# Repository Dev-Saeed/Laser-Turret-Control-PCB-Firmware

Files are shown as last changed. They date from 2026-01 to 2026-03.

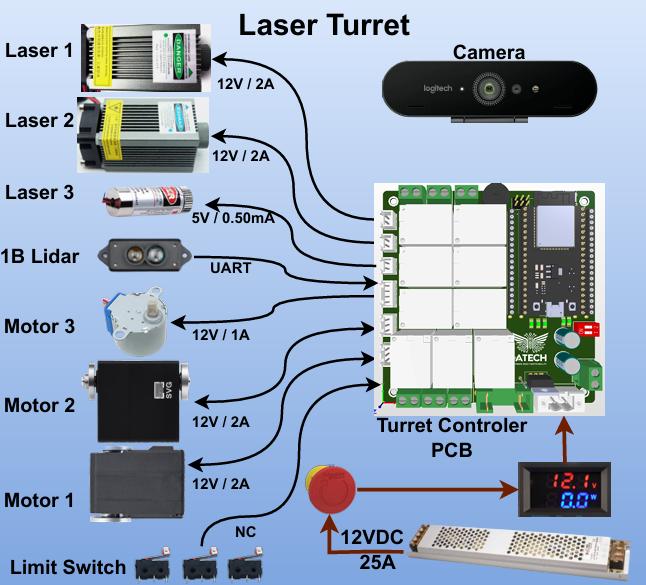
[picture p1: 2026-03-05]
Turret Component.jpg

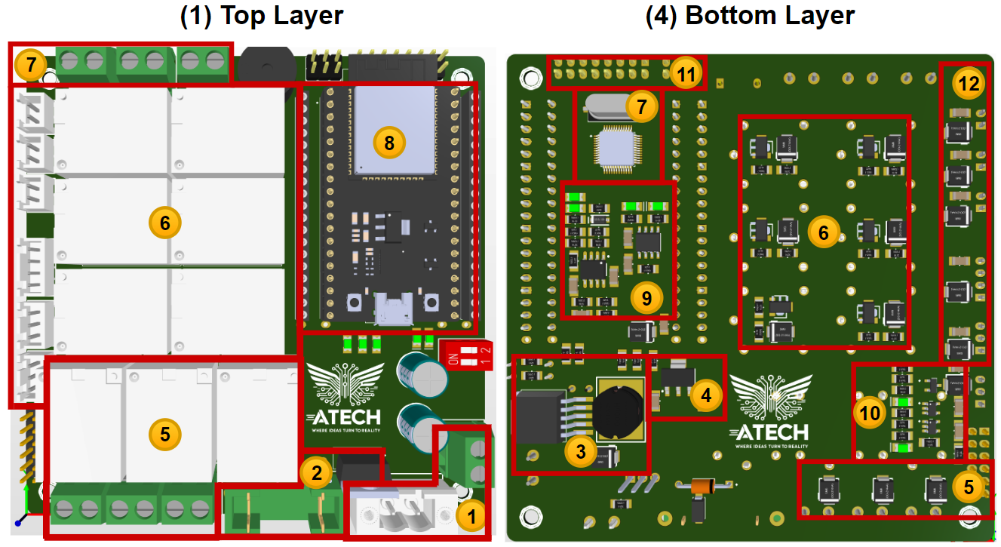
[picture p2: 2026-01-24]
PCB Files/Servo Bus Controller/Component Map.png

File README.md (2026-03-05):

# 🔧 Laser Turret – Embedded Control & PCB Firmware

> **Message Contract First.** All modules talk using **newline-delimited JSON (NDJSON)** over the selected transport (UART / RS485 / CAN with JSON payload). Each JSON object ends with `\n`. Unknown fields are ignored. Missing fields fall back to sane defaults (shown below) inside the firmware via `value | default`.

## 📨 JSON Message Contract (Over Serial/CAN)

### Transport & Framing

* **Physical/Link**: UART (TTL) • RS485 (half-duplex) • CAN (JSON in data field with simple chunking if needed)
* **Encoding**: UTF-8 JSON, **one message per line**, terminated by `\n`
* **Max payload (typ.)**: ≤ 384 bytes for `command`, ≤ 512 bytes for `status` (per current `StaticJsonDocument` sizes)
* **Clocking**: default UART `SERIAL_8N1` (baud per build config)
* **Reliability**: Higher layers may re-send last packet periodically; receivers treat each message as idempotent

---

### ▶️ Command (Control Station ESP32 ➜ Turret ESP32)

**Root shape**

```json
{
  "type": "command",
  "system_enabled": <bool>,
  "motion": {
    "pan_speed_rpm": <float>,
    "pan_min_angle": <float>,
    "pan_max_angle": <float>,
    "tilt_speed_rpm": <float>,
    "tilt_min_angle": <float>,
    "tilt_max_angle": <float>,
    "laser_focus_angle": <float>
  },
  "actuator": {
    "laser1_on": <bool>,
    "laser2_on": <bool>,
    "laser3_on": <bool>,
    "pan_motor_on": <bool>,
    "tilt_motor_on": <bool>,
    "buzzer_on": <bool>
  }
}
```

**Fields**

| Path | Type | Unit | Default | Range / Notes |
| --- | --- | --- | --- | --- |
| `type` | string | – | – | Must be `"command"`. |
| `system_enabled` | bool | – | `false` | Global soft-enable for turret logic. |
| `motion.pan_speed_rpm` | float  | rpm | `0.0` | Desired pan speed (sign = direction). |
| `motion.pan_min_angle` | float  | degrees | `0.0` | Software min limit for pan. |
| `motion.pan_max_angle` | float  | degrees | `0.0` | Software max limit for pan. |
| `motion.tilt_speed_rpm` | float  | rpm | `0.0` | Desired tilt speed (sign = direction).  |
| `motion.tilt_min_angle` | float  | degrees | `0.0` | Software min limit for tilt. |
| `motion.tilt_max_angle` | float  | degrees | `0.0` | Software max limit for tilt. |
| `motion.laser_focus_angle` | float  | degrees | `0.0` | Target focus angle (if used by optics). |
| `actuator.laser1_on` | bool | – | `false` | Relay R1. |
| `actuator.laser2_on` | bool | – | `false` | Relay R2. |
| `actuator.laser3_on` | bool | – | `false` | Relay R3 (aiming beam). |
| `actuator.pan_motor_on` | bool | – | `false` | Relay R4 (Servo/driver power). |
| `actuator.tilt_motor_on` | bool | – | `false` | Relay R5 (Servo/driver power). |
| `actuator.buzzer_on` | bool | – | `false` | Relay R6. |

**Minimal example**

```json
{"type":"command","system_enabled":true,"motion":{"pan_speed_rpm":12.0,"pan_min_angle":-90,"pan_max_angle":90,"tilt_speed_rpm":8.0,"tilt_min_angle":-30,"tilt_max_angle":45,"laser_focus_angle":5.0},"actuator":{"laser1_on":true,"laser2_on":false,"laser3_on":true,"pan_motor_on":true,"tilt_motor_on":true,"buzzer_on":false}}
```

---

### 📤 Status (Turret ESP32 ➜ Control Station / GUI)

**Root shape**

```json
{
  "type": "status",
  "motion": {
    "pan_angle_deg": <float>,
    "tilt_angle_deg": <float>,
    "pan_speed_rpm": <float>,
    "tilt_speed_rpm": <float>,
    "pan_voltage": <float>,
    "tilt_voltage": <float>
  },
  "buttons": {
    "laser_blue": <bool>,
    "laser_green": <bool>,
    "stage1": <bool>,
    "stage2": <bool>,
    "stage3": <bool>,
    "manual_mode": <bool>,
    "confirm_target": <bool>
  },
  "joystick": {
    "pot_pan": <float>,
    "pot_tilt": <float>,
    "pot_focus": <float>,
    "press": <bool>
  }
}
```

> **Note:** The code also reads `buttons.arm` when parsing status (sets `lastStatus.buttons.arm`). If you plan to surface an **arm** indicator, include it under `buttons.arm` in the sender.

**Fields**

| Path | Type | Unit | Default | Range / Notes |
| --- | --- | --- | --- | --- |
| `type` | string | – | – | Must be `"status"`. |
| `motion.pan_angle_deg` | float  | degrees | `0.0` | Measured pan angle. |
| `motion.tilt_angle_deg`  | float  | degrees | `0.0` | Measured tilt angle. |
| `motion.pan_speed_rpm` | float  | rpm | `0.0` | Measured/estimated pan speed. |
| `motion.tilt_speed_rpm`  | float  | rpm | `0.0` | Measured/estimated tilt speed. |
| `motion.pan_voltage` | float  | volts | `0.0` | Driver/sensor reading. |
| `motion.tilt_voltage` | float  | volts | `0.0` | Driver/sensor reading. |
| `buttons.laser_blue` | bool | – | `false` | Panel button state. |
| `buttons.laser_green` | bool | – | `false` | Panel button state. |
| `buttons.stage1` | bool | – | `false` | Mode stage indicator. |
| `buttons.stage2` | bool | – | `false` | Mode stage indicator. |
| `buttons.stage3` | bool | – | `false` | Mode stage indicator. |
| `buttons.manual_mode` | bool | – | `false` | Manual override active. |
| `buttons.confirm_target` | bool | – | `false` | Operator confirmation. |
| `buttons.arm`* | bool | – | `false` | (*Optional but parsed by code.) Global arm latch indicator. |
| `joystick.pot_pan` | float  | 0..1 | `0.0` | Normalized raw input. |
| `joystick.pot_tilt` | float  | 0..1 | `0.0` | Normalized raw input. |
| `joystick.pot_focus` | float  | 0..1 | `0.0` | Normalized raw input. |
| `joystick.press` | bool | – | `false` | Joystick switch. |

**Example**

```json
{"type":"status","motion":{"pan_angle_deg":14.2,"tilt_angle_deg":-3.5,"pan_speed_rpm":10.7,"tilt_speed_rpm":7.9,"pan_voltage":11.8,"tilt_voltage":11.7},"buttons":{"arm":true,"laser_blue":false,"laser_green":true,"stage1":true,"stage2":false,"stage3":false,"manual_mode":false,"confirm_target":true},"joystick":{"pot_pan":0.41,"pot_tilt":0.58,"pot_focus":0.12,"press":false}}
```

---

### Parsing & Robustness Rules

* Messages without `type` are **ignored**.
* Unknown fields are **ignored** (for forward compatibility).
* On `type: "command"` and `type: "status"`, missing inner fields use defaults shown above.
* Receiver processes a full message **only at newline**; partial lines are buffered.
* **Validation**: basic deserialization error check; invalid JSON is dropped silently.
* **Versioning** (recommended): add `"schema":"1.0"` at root in future revisions; receivers should ignore if absent.

---

## 📦 Repository Structure

```bash
├── firmware/
│   ├── control_station_esp32/        # Control station (joystick, buttons, PC communication)
│   │   ├── include/                  # Header files
│   │   │   ├── JsonMessenger.h
│   │   │   └── StationConfig.h
│   │   ├── src/                      # Source files
│   │   │   ├── JsonMessenger.cpp
│   │   │   ├── StationConfig.cpp
│   │   │   └── main.cpp
│   │   ├── lib/                      # External libraries
│   │   └── README
│   │
│   ├── turret_esp32/                 # Main turret logic (motors, laser, feedback)
│   │   ├── include/                  # Header files
│   │   │   ├── JsonMessenger.h
│   │   │   ├── STM_Link.h
│   │   │   ├── SerialSpeedInput.h
│   │   │   ├── TurretConfig.h
│   │   │   ├── ddl_servo.h
│   │   │   ├── nema_driver.h
│   │   │   ├── physics.h
│   │   │   ├── st_driver.h
│   │   │   └── stepper_focus_driver.h
│   │   ├── src/                      # Source files
│   │   │   ├── JsonMessenger.cpp
│   │   │   ├── STM_Link.cpp
│   │   │   ├── TurretConfig.cpp
│   │   │   ├── ddl_servo.cpp
│   │   │   ├── nema_driver.cpp
│   │   │   ├── physics.cpp
│   │   │   ├── st_driver.cpp
│   │   │   ├── stepper_focus_driver.cpp
│   │   │   └── main.cpp
│   │   ├── lib/                      # External libraries (Servo, Dynamixel, etc.)
│   │   │   ├── Dynamixel2Arduino/
│   │   │   ├── SCServo/
│   │   │   └── ServoDriverST/
│   │   └── test/
│   │
│   └── turret_stm32/                 # Low-level I/O, relays, limit switches
│       ├── Core/                     # Application core (HAL, main loop)
│       ├── Drivers/                  # STM32 HAL & BSP drivers
│       ├── metadata/                 # Project metadata
│       ├── settings/                 # Build / configuration files
│       └── Debug/
│
├── pcb/
│   └── turret_control_station_pcb_design/   # Shared PCB for turret & control station
│
├── docs/
│   └── readme_assets/                # Diagrams, schematics, images
│
└── README.md

---

## 🧠 System Architecture

Two microcontroller nodes coordinate turret control and safety via serial messaging.

### 1) ESP32 – Control Station Module

**Reads**

* 3-axis joystick + buttons (GPIO)

**Receives**

* Target parameters from laptop (CV module)

**Sends**

* `command` JSON to Turret Unit (UART / Modbus / CAN)

**Inputs from Laptop**

* Pan/Tilt (angle/velocity), laser enable, mode toggles, buzzer

---

### 2) ESP32 – Turret Unit Module

**Receives**

* `command` JSON from Control Station

**Controls**

* **Relays**: laser modules (x3), servo power (x2), buzzer
* **Pan/Tilt servos** over RS485 (half-duplex, vendor protocol)
* **Stepper motor** (driver or direct)

**Communicates**

* UART with **STM32** for relay/limit I/O
* Sends `status` JSON back to Control Station

**Feedback**

* Motor angles/speeds/temperatures, relay states, safety flags

---

### 3) STM32F0 – Turret Relay & Safety Controller

**Functions**

* Drives **6 relays** via GPIO + transistor stages
* Reads **limit switches** (NO type)
* Handles **EMG** switches that cut **12 V** power electrically (out of MCU loop)

**Relay Map**

| Relay | Load                |
| ----: | ------------------- |
|    R1 | Laser Module 1      |
|    R2 | Laser Module 2      |
|    R3 | Laser Aiming Beam   |
|    R4 | Servo Motor 1 Power |
|    R5 | Servo Motor 2 Power |
|    R6 | Buzzer              |

---

## ⚡ Power & Safety

**Input**: 12 V DC
**Regulation**: 12→5 V (buck), 5→3.3 V (LDO)

**Global Power Relays**

| Relay Group | Purpose                         |
| ----------- | ------------------------------- |
| Main        | Master enable for all actuators |
| Motor       | Enables R4–R5 (servo/driver)    |
| Laser       | Enables R1–R3 (lasers)          |

**Emergency Interfaces**

* External EMG/limit contacts in series with relay coils
* **Closed = enabled**, **open = immediate power cut** to the group

---

## 🔁 Links & Protocols

**Control Station ⇄ Turret**: UART / Modbus (RS485) / CAN; payload is the JSON `command`/`status` above.
**Turret ⇄ STM32**: UART, compact custom messages for relay toggles + limit switch feedback (JSON or binary, depending on build).

---

## 🛠️ Feature Highlights

* ✅ One **unified PCB** used in **both modules**
* ✅ Clean module split: **control**, **execution**, **relay/safety**
* ✅ Multi-bus comms: **Serial**, **Modbus**, **CAN**
* ✅ Hardware **EMG** cutoffs for lasers & motors
* ✅ Manual / CV / Hybrid control modes
* ✅ GPIO headroom for future sensors/actuators

---

## 🧪 Getting Started (Soon)

Step-by-step flashing & wiring guides for:

* ESP32 (Control Station)
* ESP32 (Turret Unit)
* STM32 (Relay Controller)

---

## 🧩 Implementation Notes (from `JsonMessenger`)

* `begin()` sets port & reserves ~512 B buffer.
* `sendCommand()` / `sendStatus()` build JSON via ArduinoJson and append `\n`.
* `receive()` buffers until newline, then `processMessage()`.
* `processMessage()` validates `type` and populates `lastCommand` / `lastStatus`.
* Document sizes: `StaticJsonDocument<384>` (command/status send) and `StaticJsonDocument<512>` (receive/parse).

> **Consistent Button Set:** The parser reads `buttons.arm` in `status`; if you want this latched in UI/safety, emit it from the sender.

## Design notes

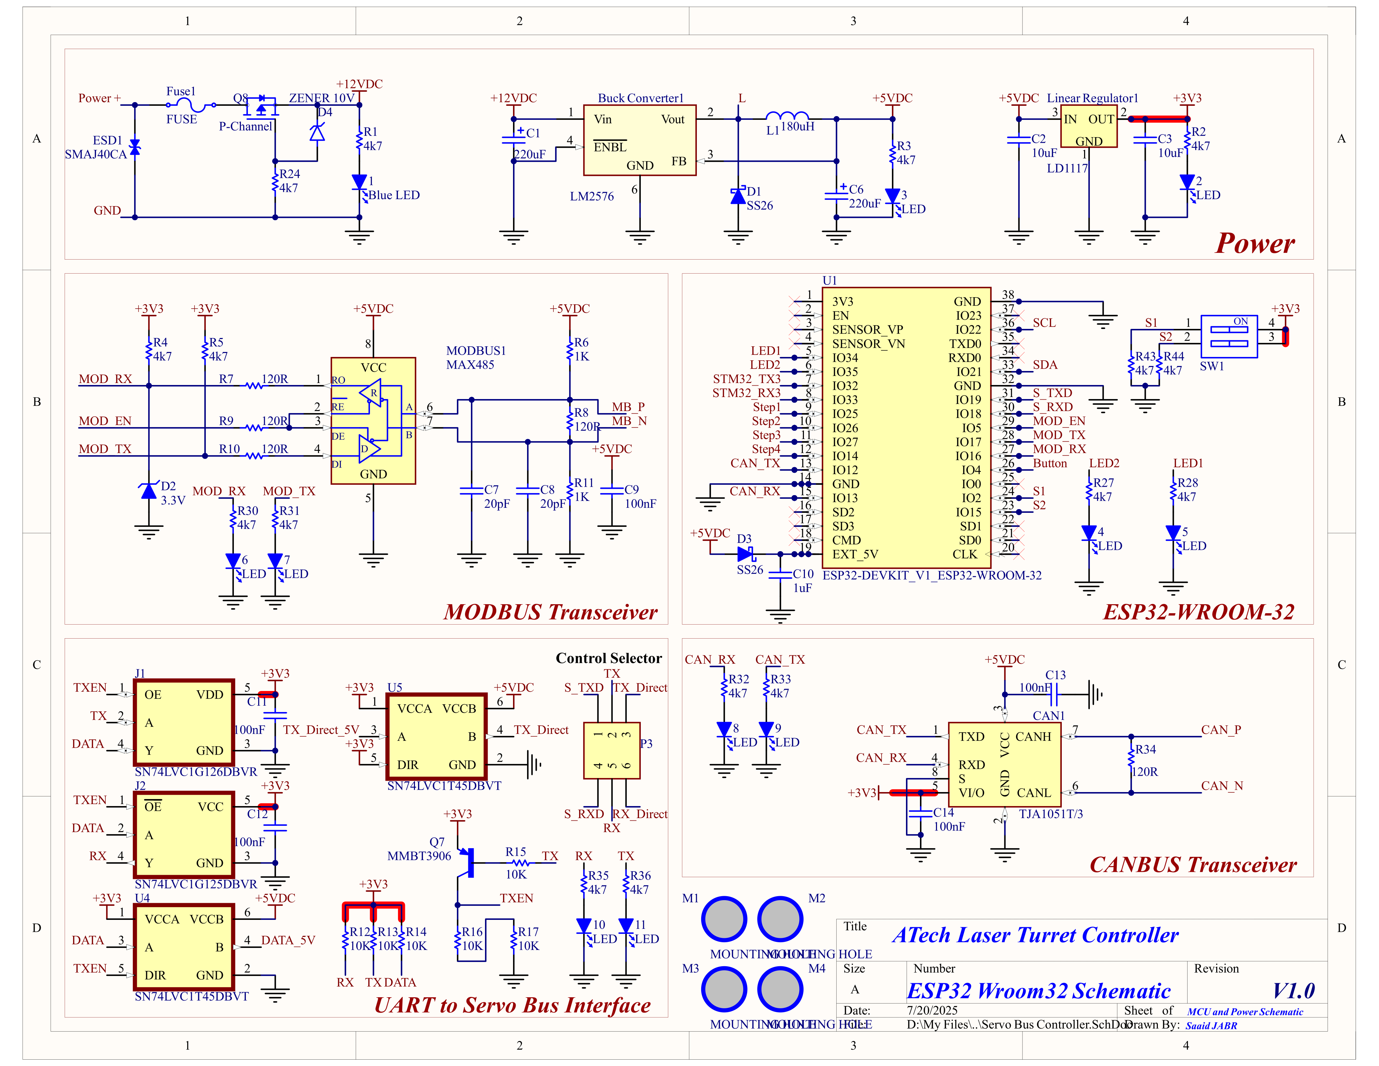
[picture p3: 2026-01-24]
PCB Files/Servo Bus Controller/Laser Turret Controller Schematic - Page 1.png

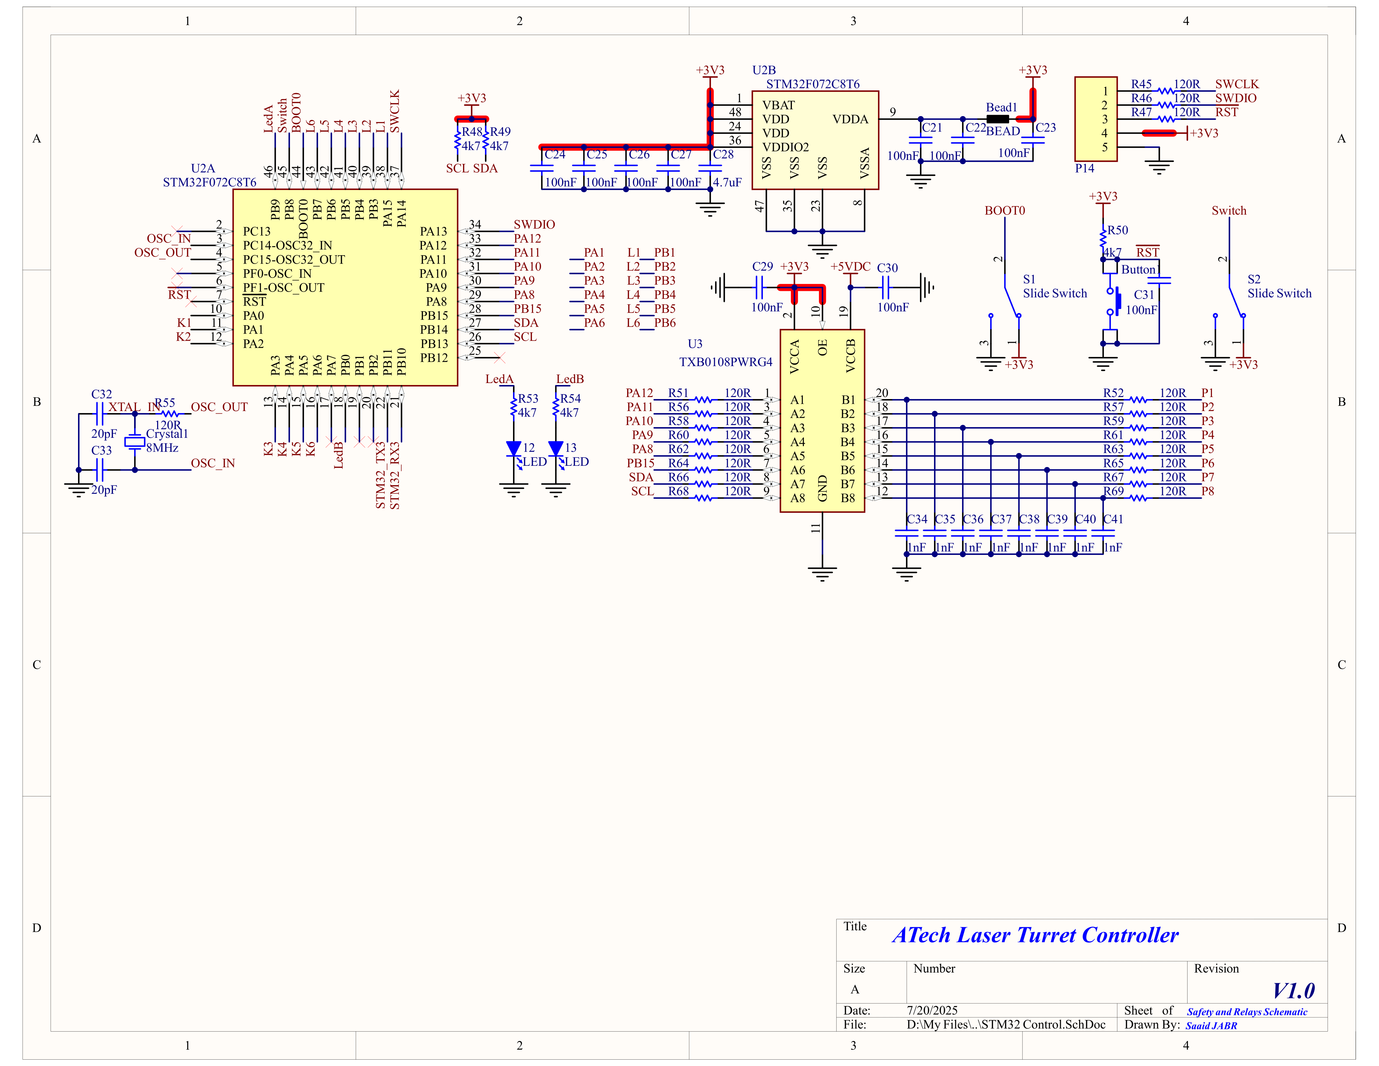
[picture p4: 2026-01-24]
PCB Files/Servo Bus Controller/Laser Turret Controller Schematic - Page 2.png

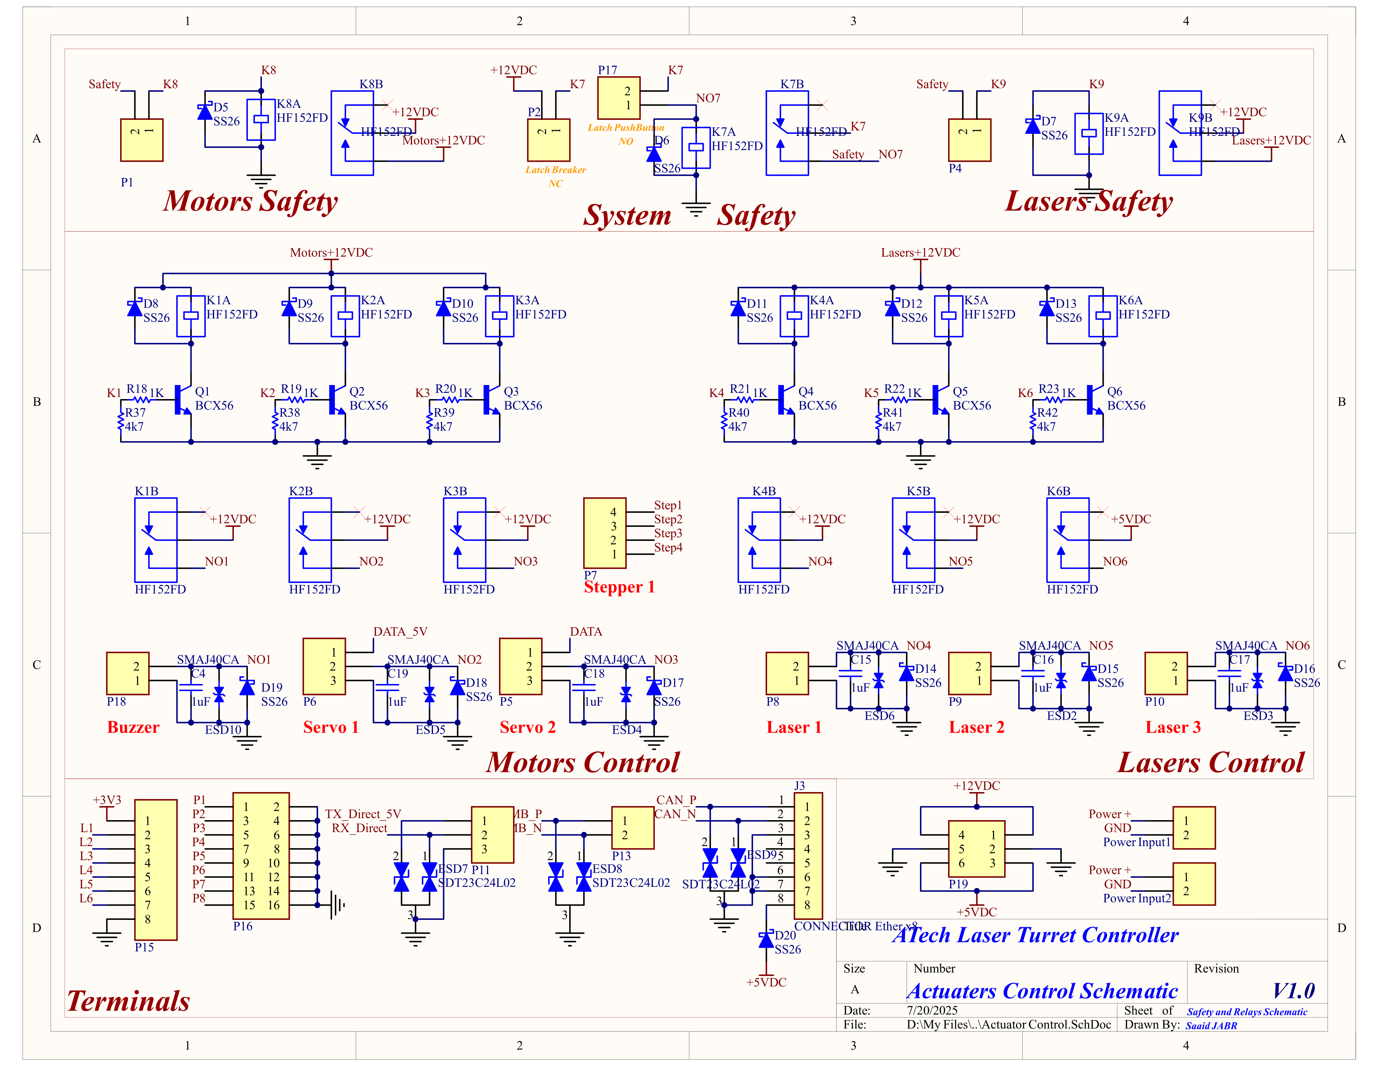
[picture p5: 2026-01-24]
PCB Files/Servo Bus Controller/Laser Turret Controller Schematic - Page 3.png

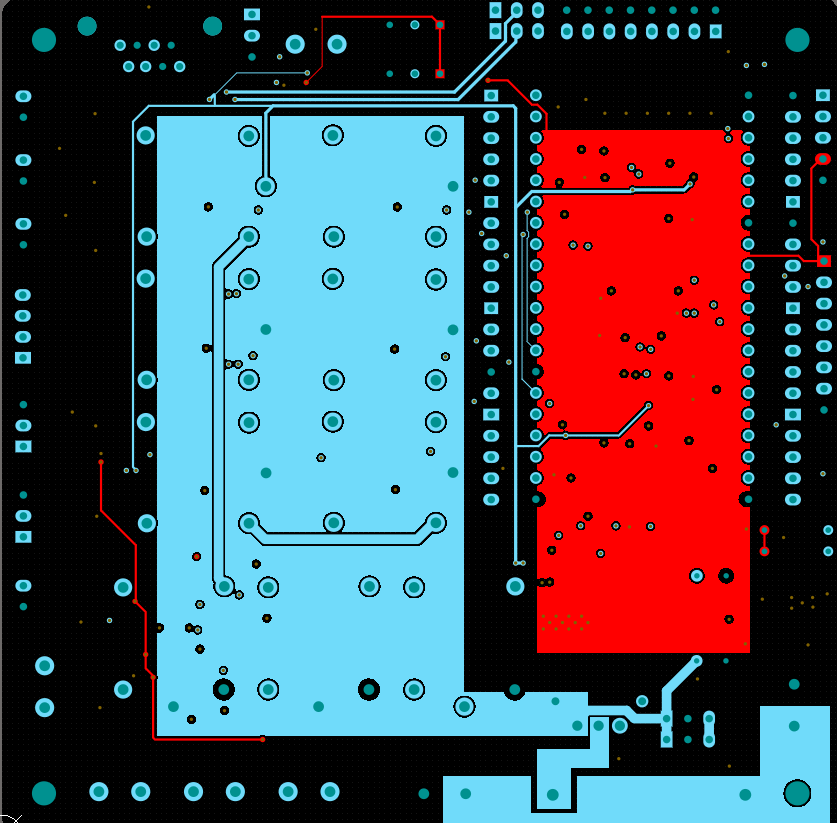
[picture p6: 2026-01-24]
PCB Files/Servo Bus Controller/Layout-POWER Layer.png

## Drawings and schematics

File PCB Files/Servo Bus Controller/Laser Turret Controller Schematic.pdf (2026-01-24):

# Power

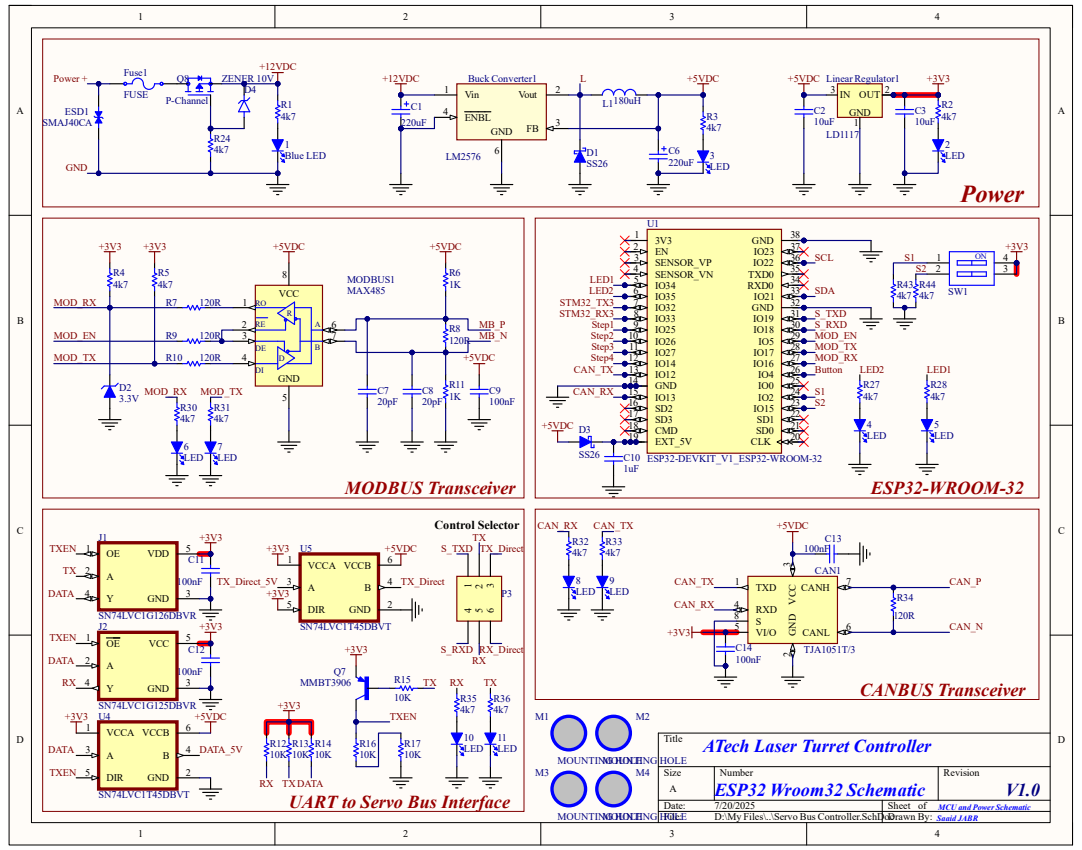
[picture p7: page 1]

Title
ATech Laser Turret Controller

UART to Servo Bus Interface

MCU and Power Schematic
Saaid JABR

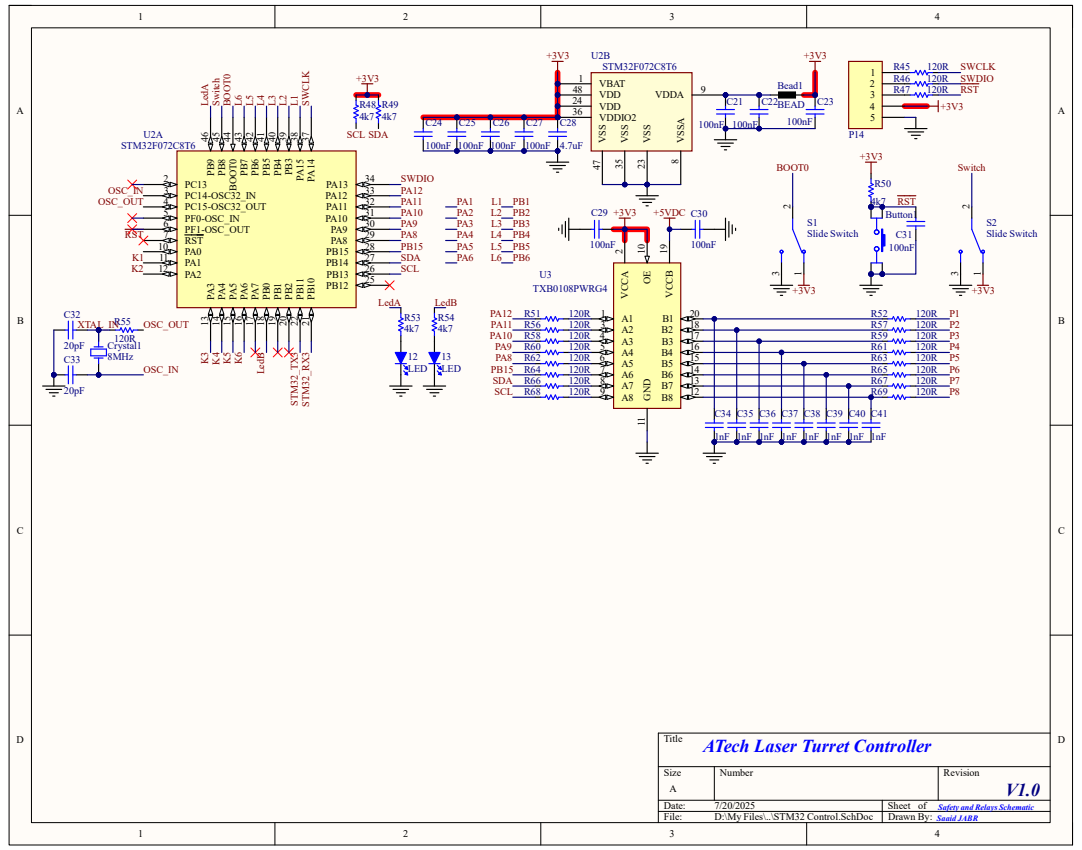
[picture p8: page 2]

Title
ATech Laser Turret Controller

Safety and Relays Schematic

System | Safety
Motors Safety | Lasers Safety

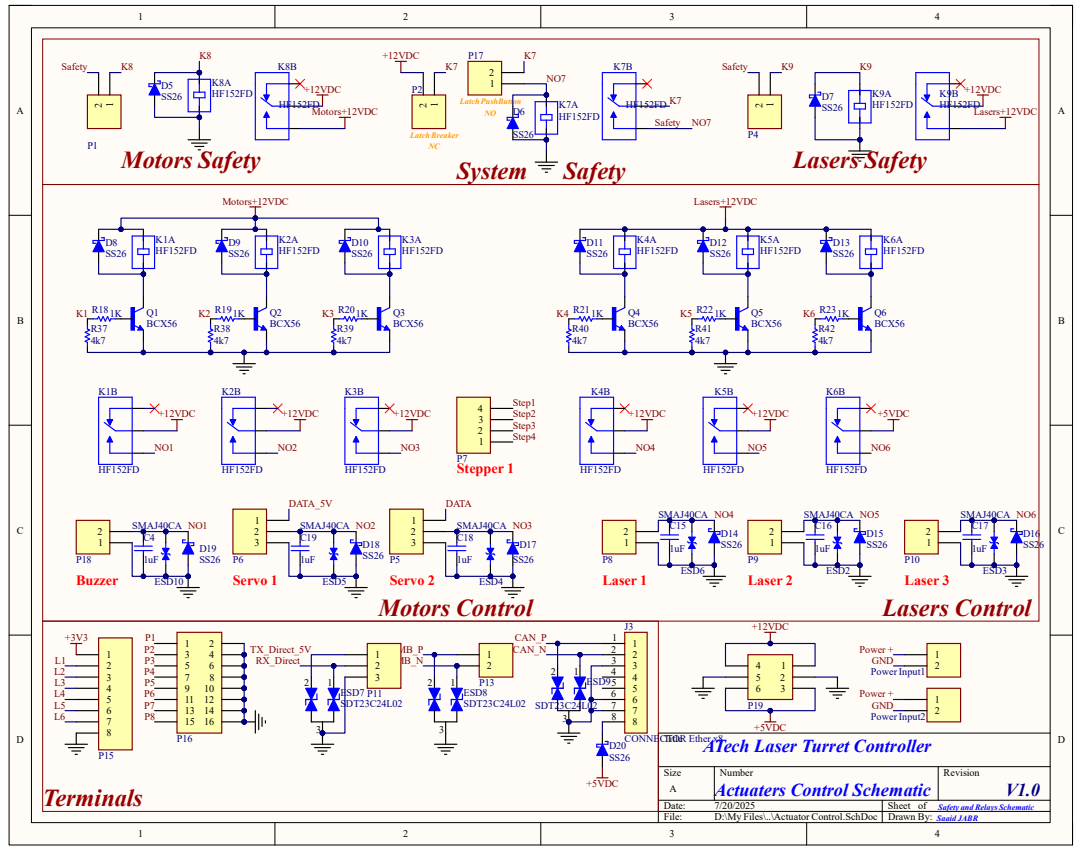
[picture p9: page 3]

Safety and Relays Schematic

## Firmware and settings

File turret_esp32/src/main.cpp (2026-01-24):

#include <Arduino.h>
#include "JsonMessenger.h"
#include "st_driver.h"
#include "nema_driver.h"
#include "physics.h"
#include "TurretConfig.h"
#include "STM_Link.h"
#include "SerialSpeedInput.h"
// #include "stepper_focus_driver.h"

STM_Link stmLink;
JsonMessenger stationMessenger;

unsigned long lastRelaySendTime = 0;
const unsigned long relayIntervalMs = 5;

void setup() {
  setupConfig();

  DEBUG_SERIAL.begin(DEBUG_BAUDRATE, SERIAL_8N1, DEBUG_RX, DEBUG_TX);

  // === Communication Setup ===
  stmLink.beginUART(STM32_SERIAL, STM32_BAUDRATE, STM32_RX3, STM32_TX3);
  stationMessenger.begin(station_SERIAL, station_BAUDRATE, station_RX, station_TX);
  delay(200);

  // === Motor Setup ===
  init_ST(Servo_SERIAL, SERVO_BAUDRATE, S_RX, S_TX); // Tilt motor (servo)
  init_NEMA(EN_PIN, DIR_PIN, STEP_PIN, COM_PIN, LIMIT_PIN, STEPS_PER_REV); // Pan motor (stepper)
  delay(200);

  // Enable relays for motors
  stm_output[2] = 1; // Motor1 (Pan)
  stm_output[1] = 1; // Motor2 (Tilt)
  stmLink.sendRelayStates(stm_output);
  // init_BYJ(STEP1, STEP2, STEP3, STEP4);
  delay(1000);

  // === Homing Motors ===
  st_writeByte_eeprom(1, 18, 45); // Set phase value to 128
  Tilt_home();
  // st_reset();
  Pan_home();
  // Focus_home();
  delay(2000);
  delay(100);

  // st_OP_VELOCITY(); // Enable servo velocity control mode
  Pan_goTo(160);
  Pan_goTo(140);
}

void loop() {
  unsigned long t0 = micros();

  // === (1) Receive command from Control Station ===
  stationMessenger.receive();

  // === (2) Read limit switches from STM32 ===
  stmLink.readLimitStates(stm_input);

  // === (3) Parse and apply command ===
  if (stationMessenger.lastCommand.valid) {
    const ControlCommand &cmd = stationMessenger.lastCommand;

    Buzzer  = cmd.actuator.buzzer_on;
    Motor1  = cmd.actuator.pan_motor_on;
    Motor2  = cmd.actuator.tilt_motor_on;
    Laser1  = cmd.actuator.laser1_on;
    Laser2  = cmd.actuator.laser2_on;
    Laser3  = cmd.actuator.laser3_on;
    // Focus   = cmd.actuator.focus_on;

    pan_target_speed  = cmd.motion.pan_speed_rpm;
    tilt_target_speed = cmd.motion.tilt_speed_rpm;
    lseres_focus_angle = cmd.motion.laser_focus_angle;
  }

  // === (4) Update relay outputs ===
  stm_output[0] = Buzzer || stm_input[6];
  stm_output[2] = 1;       // Motor1 always enabled
  stm_output[1] = 1;       // Motor2 always enabled
  stm_output[3] = Laser1 || stm_input[6];
  stm_output[4] = Laser2;
  stm_output[5] = 1;
  stm_output[6] = stm_input[6];
  stm_output[7] = Laser3;

  if (!(pan_getAngle() > 125 && pan_getAngle() < 155)) {
  stm_output[0] = 0; // Buzzer
  stm_output[3] = 0; // Laser1
  stm_output[4] = 0; // Laser2
  // stm_output[5] = 0; // Laser3
  }

  if (millis() - lastRelaySendTime >= relayIntervalMs) {
  stmLink.sendRelayStates(stm_output);
  lastRelaySendTime = millis();
  } 
  digitalWrite(LED_BUILTIN, Laser3); // Debug LED

  // === (5) Apply motion control ===
  // handleSerialSpeeds(pan_target_speed, tilt_target_speed);
  nema_pan_speed_control(pan_target_speed, PAN_ANGLE_MIN, PAN_ANGLE_MAX);
  st_tilt_speed_control(tilt_target_speed, TILT_ANGLE_MIN, TILT_ANGLE_MAX);
  // if (Focus == 1) {
  //   stepper_aim_angle_control(lseres_focus_angle, FOCUS_ANGLE_MIN, FOCUS_ANGLE_MAX);
  // }
  
  // === (6) (Optional) Read motor feedback ===
  // pan_current_angle  = pan_getAngle();
  tilt_current_angle = tilt_getAngle();
  // pan_current_speed  = pan_getVelocity();
  // tilt_current_speed = tilt_getVelocity();
  // pan_current_voltage  = tilt_getVoltage();
  // tilt_current_voltage = tilt_getVoltage();

  // === (7) (Optional) Send status back to Station ===
  // TurretStatus status;
  // status.motion.pan_angle_deg  = pan_current_angle;
  // status.motion.tilt_angle_deg = tilt_current_angle;
  // status.motion.pan_speed_rpm  = pan_current_speed;
  // status.motion.tilt_speed_rpm = tilt_current_speed;
  // status.motion.pan_voltage    = pan_current_voltage;
  // status.motion.tilt_voltage   = tilt_current_voltage;
  // stationMessenger.sendStatus(status);

  unsigned long loopTime = micros() - t0;
  // DEBUG_SERIAL.println(tilt_current_angle);
  // st_read_eeprom(); 
  // delay(2000);
}

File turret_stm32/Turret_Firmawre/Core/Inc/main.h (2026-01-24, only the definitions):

#define K1_Pin GPIO_PIN_1
#define K1_GPIO_Port GPIOA
#define K2_Pin GPIO_PIN_2
#define K2_GPIO_Port GPIOA
#define K3_Pin GPIO_PIN_3
#define K3_GPIO_Port GPIOA
#define K4_Pin GPIO_PIN_4
#define K4_GPIO_Port GPIOA
#define K5_Pin GPIO_PIN_5
#define K5_GPIO_Port GPIOA
#define K6_Pin GPIO_PIN_6
#define K6_GPIO_Port GPIOA
#define LedB_Pin GPIO_PIN_0
#define LedB_GPIO_Port GPIOB
#define IO8_Pin GPIO_PIN_13
#define IO8_GPIO_Port GPIOB
#define IO7_Pin GPIO_PIN_14
#define IO7_GPIO_Port GPIOB
#define IO6_Pin GPIO_PIN_15
#define IO6_GPIO_Port GPIOB
#define IO5_Pin GPIO_PIN_8
#define IO5_GPIO_Port GPIOA
#define IO4_Pin GPIO_PIN_9
#define IO4_GPIO_Port GPIOA
#define IO3_Pin GPIO_PIN_10
#define IO3_GPIO_Port GPIOA
#define IO2_Pin GPIO_PIN_11
#define IO2_GPIO_Port GPIOA
#define IO1_Pin GPIO_PIN_12
#define IO1_GPIO_Port GPIOA
#define L1_Pin GPIO_PIN_15
#define L1_GPIO_Port GPIOA
#define L2_Pin GPIO_PIN_3
#define L2_GPIO_Port GPIOB
#define L3_Pin GPIO_PIN_4
#define L3_GPIO_Port GPIOB
#define L4_Pin GPIO_PIN_5
#define L4_GPIO_Port GPIOB
#define L5_Pin GPIO_PIN_6
#define L5_GPIO_Port GPIOB
#define L6_Pin GPIO_PIN_7
#define L6_GPIO_Port GPIOB
#define Switch_Pin GPIO_PIN_8
#define Switch_GPIO_Port GPIOB
#define LedA_Pin GPIO_PIN_9
#define LedA_GPIO_Port GPIOB

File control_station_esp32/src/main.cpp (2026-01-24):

/*
  Main control code for the Control Station ESP32.
  This code performs the following main tasks in each loop iteration:

  1. Receive and parse incoming JSON status from the Turret (via UART0/USB).
  2. Read local buttons and joystick, fill them into the status.
  3. Send the completed status JSON to the gui (via UART1).

  4. Receive and parse incoming JSON command from the gui (via UART1).
  5. Forward the command JSON directly to the Turret (via UART0/USB).

  The setup() function initializes communications and configures I/O.

  To Run it using PlatformIO:
  pio run -e ControlStation -t clean && pio run -e ControlStation && pio run -e ControlStation -t upload && pio device monitor -e ControlStation

*/
 
#include <Arduino.h>
#include "JsonMessenger.h"
#include "StationConfig.h"

// Two messengers: one for each UART
JsonMessenger turretMessenger;  // for USB/UART0 (Turret)
JsonMessenger guiMessenger;  // for UART1 (gui)

void setup() {
  setupConfig();

  // Initialize UART0 for Turret
  // turretMessenger.begin(turret_SERIAL, turret_BAUDRATE, turret_RX, turret_TX); //Default turretMassenger
  // Initialize UART1 for gui
  guiMessenger.begin(gui_SERIAL, gui_BAUDRATE, gui_RX, gui_TX); //Default guiMassenger
  delay(200);  
}

void loop() {
  // ---------------- (1) Receive status from Turret ----------------
  // turretMessenger.receive(); 

  // if (turretMessenger.lastStatus.valid || 1) {
    // Copy motion info from Turret
    // TurretStatus status = turretMessenger.lastStatus;
    TurretStatus status;

    // ---------------- (2) Read local buttons ----------------
    status.buttons.arm          = !digitalRead(BTN_ARM);
    status.buttons.laser_blue   = !digitalRead(BTN_LASER_BLUE);
    status.buttons.laser_green  = !digitalRead(BTN_LASER_GREEN);

    bool stageA = !digitalRead(BTN_STAGE_A);
    bool stageB = !digitalRead(BTN_STAGE_B);
    status.buttons.stage1 = false;
    status.buttons.stage2 = false;
    status.buttons.stage3 = false;
    if (stageA && !stageB)      status.buttons.stage1 = true;
    else if (!stageA && stageB) status.buttons.stage2 = true;
    else if (stageA && stageB)  status.buttons.stage3 = true;

    status.buttons.manual_mode   = !digitalRead(BTN_MANUAL);
    status.buttons.confirm_target = !digitalRead(BTN_CONFIRM);

    // ---------------- (3) Read joystick ----------------
    status.joystick.pot_pan   = readJoystickAxis(JOY_POT_PAN);
    status.joystick.pot_tilt  = readJoystickAxis(JOY_POT_TILT);
    status.joystick.pot_focus = readJoystickAxis(JOY_POT_FOCUS);
    status.joystick.press     = !digitalRead(JOY_BTN_PRESS);

    // ---------------- (4) Send status to gui ----------------
    guiMessenger.sendStatus(status);
    delay(300);
  // }

  // ---------------- (5) Receive command from gui and forward to Turret ----------------
  // guiMessenger.receive();
  // if (guiMessenger.lastCommand.valid || 1) {
  //   ControlCommand guicmd = guiMessenger.lastCommand;

  //   // ------------StartTest----------
  //   guicmd.actuator.buzzer_on = !digitalRead(BTN_ARM);
  //   guicmd.actuator.laser3_on = !digitalRead(BTN_LASER_GREEN);
  //   guicmd.actuator.laser1_on = !digitalRead(BTN_LASER_BLUE) || guicmd.actuator.laser1_on;

  //   float panRPM  = map(readJoystickAxis(JOY_POT_PAN), -100, 100, -5, 5);
  //   float tiltRPM = map(readJoystickAxis(JOY_POT_TILT), -100, 100, -5, 5);

  //   guicmd.motion.pan_speed_rpm = panRPM;
  //   guicmd.motion.tilt_speed_rpm = tiltRPM;
  //   // ------------EndTest----------

  //   turretMessenger.sendCommand(guicmd);
  //   delay(10);
  // }
}

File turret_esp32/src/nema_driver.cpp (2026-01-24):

#include "nema_driver.h"
#include "driver/timer.h"

// Internal static variables
static int en_pin_local, dir_pin_local, step_pin_local, com_pin_local, limit_pin_local;
static float steps_per_rev_local = 1600.0f;
static float pan_gear_ratio = 185.0f / 35.0f;
static AccelStepper stepper(AccelStepper::DRIVER, 0, 0);
static float currentAngle = 0.0f;

// Timer variables
hw_timer_t *stepperTimer = NULL;
portMUX_TYPE timerMux = portMUX_INITIALIZER_UNLOCKED;

// Timer ISR — optional if you want continuous motion (currently not used)
void IRAM_ATTR onStepperTimer() {
    portENTER_CRITICAL_ISR(&timerMux);
    stepper.runSpeed();
    portEXIT_CRITICAL_ISR(&timerMux);
}

void init_NEMA(int enPin, int dirPin, int stepPin, int comPin, int limitPin, float stepsPerRev) {
    en_pin_local = enPin;
    dir_pin_local = dirPin;
    step_pin_local = stepPin;
    limit_pin_local = limitPin;
    steps_per_rev_local = stepsPerRev;
    com_pin_local = comPin;

    pinMode(en_pin_local, OUTPUT);
    digitalWrite(en_pin_local, LOW); // Enable driver

    pinMode(limit_pin_local, INPUT_PULLUP);
    pinMode(com_pin_local, OUTPUT);
    digitalWrite(com_pin_local, LOW); // Set COM pin low

    stepper = AccelStepper(AccelStepper::DRIVER, step_pin_local, dir_pin_local);
    stepper.setMaxSpeed(3000);
    stepper.setAcceleration(2000);

    // Optional: Enable timer interrupt if needed
    // stepperTimer = timerBegin(0, 80, true);
    // timerAttachInterrupt(stepperTimer, &onStepperTimer, true);
    // timerAlarmWrite(stepperTimer, 2000, true); // 2ms
    // timerAlarmEnable(stepperTimer);
}

// ----- Homing -----
void Pan_home() {
    stepper.setMaxSpeed(500);
    stepper.setSpeed(-500);
    while (digitalRead(limit_pin_local) == LOW) {
        stepper.runSpeed(); // Blocking
        delay(1);
    }
    
    stepper.setCurrentPosition(0);
    currentAngle = 0.0f;

    while (digitalRead(limit_pin_local) == LOW) {
        stepper.runSpeed(); // Blocking
        delay(1);
    }
}

// ----- Move to specific angle -----
void Pan_goTo(float panAngleDeg) {
    float motorAngle = panAngleDeg * pan_gear_ratio;
    long targetSteps = (long)((motorAngle / 360.0f) * steps_per_rev_local);

    stepper.setMaxSpeed(1200);
    stepper.setAcceleration(800);
    stepper.moveTo(targetSteps);
    stepper.runToPosition(); // Blocking
    currentAngle = panAngleDeg;
}

// ----- Calibration routine -----
void Pan_Calibrate() {
    Pan_home();
    Pan_goTo(135.0f);
    delay(10000);
    Pan_goTo(145.0f);
    delay(200);
}

// ----- Speed Control (call from loop) -----
void nema_pan_speed_control(float rpmCommand, float minAngle, float maxAngle) {
    if (rpmCommand > PAN_SPEED_MAX) rpmCommand = PAN_SPEED_MAX;
    if (rpmCommand < -PAN_SPEED_MAX) rpmCommand = -PAN_SPEED_MAX;

    float motorRpm = rpmCommand * pan_gear_ratio;
    float stepsPerSec = (motorRpm * steps_per_rev_local) / 60.0f;
    stepper.setSpeed(stepsPerSec);

    float stepAngle = (stepsPerSec > 0 ? 1 : -1) * (360.0f / steps_per_rev_local);
    float nextAngle = currentAngle + stepAngle;

    float minMotorAngle = minAngle * pan_gear_ratio;
    float maxMotorAngle = maxAngle * pan_gear_ratio;

    if ((stepsPerSec > 0 && nextAngle > maxMotorAngle) ||
        (stepsPerSec < 0 && nextAngle < minMotorAngle)) {
        stepper.setSpeed(0);
    } else {
        // ✅ Update angle only if a step was taken
        if (stepper.runSpeed()) {
            currentAngle = nextAngle;
        }
    }
}

// ----- Getters -----
float pan_getAngle() {
    return currentAngle / pan_gear_ratio;
}

float pan_getVelocity() {
    float motorRpm = stepper.speed() * 60.0f / steps_per_rev_local;
    return motorRpm / pan_gear_ratio;
}

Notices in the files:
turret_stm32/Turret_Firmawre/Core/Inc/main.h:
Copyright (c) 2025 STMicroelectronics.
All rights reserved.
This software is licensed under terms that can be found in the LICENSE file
